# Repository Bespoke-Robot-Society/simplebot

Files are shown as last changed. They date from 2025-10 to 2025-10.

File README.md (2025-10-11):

# SimpleBot

Bespoke Robot Society's original design for kids, students, or cost-sensitive tinkerers.

Image of SimpleBot

Goals:

* Control a basic, multipurpose teaching robot with the Pi Pico (or Pico W).
* Demonstrate **optical odometry** - measuring the distance wheels turn by counting pulses on light sensors.
* Demonstrate **line following** - steer the robot in response to reflectance sensors that give the position of the line.
* Leave pins open on the microcontroller for additional upgrades.
* **Do not exceed $20 in price, with batteries included.**

## Hardware

Simplebot is based on the "Arduino Smart Car" kit that can be found on Amazon or Aliexpress. This provides a caster wheel, two yellow "TT" motors with optical encoder wheels and actual wheels, a power switch, and a 4xAA battery case. (~$6)

For line detectors, a generic "Infrared Obstacle Avoidance Sensor" module can be found in the US for 20 for $10 - SimpleBot requires two ($1).

Microcontroller - Raspberry Pi Pico ($4) or Raspberry Pi Pico W ($6).

Motor Controller - The TB6612FNG dual H-bridge module. You might be able to find this for $1 or less from overseas, but 3 for $9 is available in the US. ($3)

The optical encoder module requires one LED, one photoresistor, five resistors, and one LM393 chip for both. I don't know the prices for these, as I had them on hand.

an MPU6050 (Accelerometer/gyroscope) and nRF24l01 (2.4GHz radio module) are included on the circuit board, but haven't been tested or programmed yet. These occupy the I2C and SPI buses respectively, and would play well with some additional sensors (at the cost of spare pins for more SPI devices).

## Circuit Board

A through-hole (THT) PCB design is available for easy assembly.

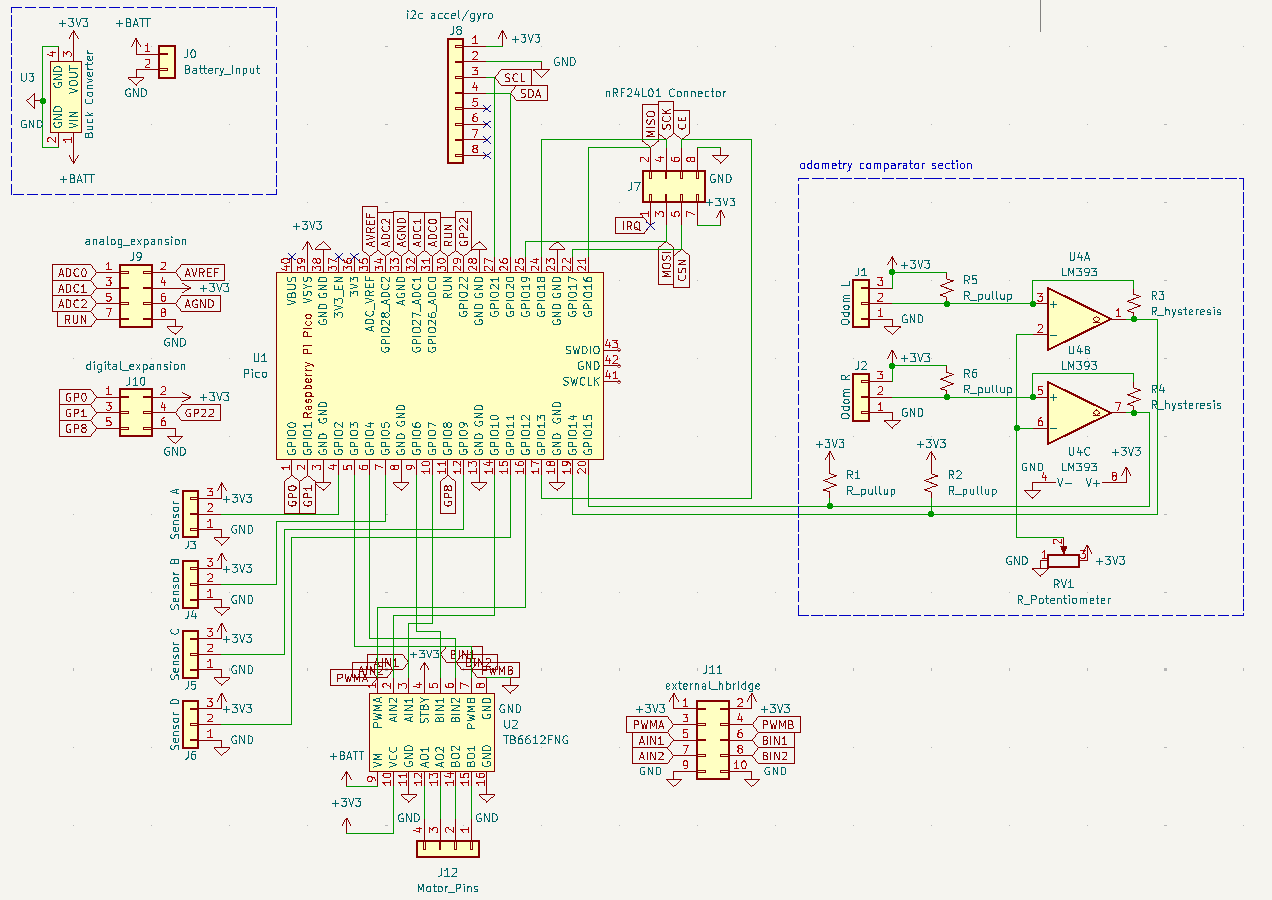
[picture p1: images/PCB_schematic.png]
PCB Schematic


The PCB integrates:
- Raspberry Pi Pico microcontroller (or compatible)
- TB6612FNG motor driver (or external H-bridge support)
- Buck converter for power regulation
- LM393-based optical encoder circuit
- Headers for nRF24L01 radio and MPU6050 IMU
- 4 sensor headers for expansion
- Analog and digital GPIO breakouts

See [PCB_GUIDE.md](PCB_GUIDE.md) for detailed PCB documentation.

See [ASSEMBLY_GUIDE.md](ASSEMBLY_GUIDE.md) for mechanical assembly instructions. 

## Software

Copy the included files to your Pi Pico by USB cable. I used Thonny to test the robot's programs.

# Future Work

Should I switch to an off-the-shelf optical encoder module, or should I build a custom line detecting sensor?

Printed circuit boards:

* Through hole soldering kit
* a board-on-board PCB - same layout as the protoboard, but soldered flat together.
* a custom PCB that uses the ICs from the modules directly

SimpleBot is unfortunately too large for standard micromouse mazes, so a "simplebot mini" seems to be in order.

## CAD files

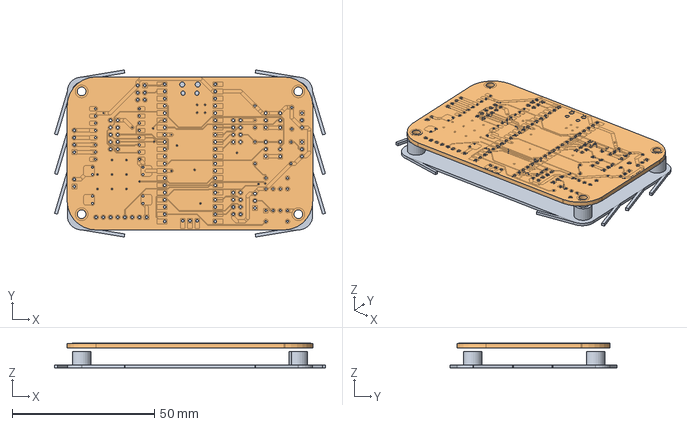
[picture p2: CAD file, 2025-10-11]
diffdrive_PCB_export.FCStd
95.3 x 58.8 x 8.63 mm
Heat_Set_Insert_Version
diffdrive_robot_microcontroller_board 002

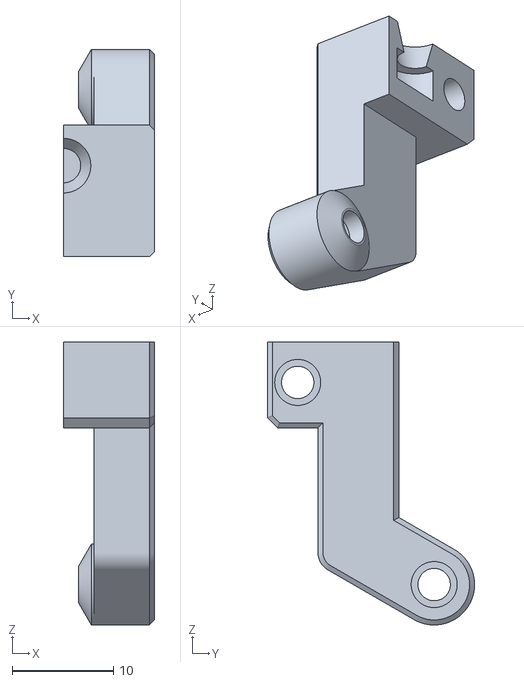
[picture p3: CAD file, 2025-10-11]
STL/Simplebot_caster_rotor.stl
9.00 x 20.5 x 28.0

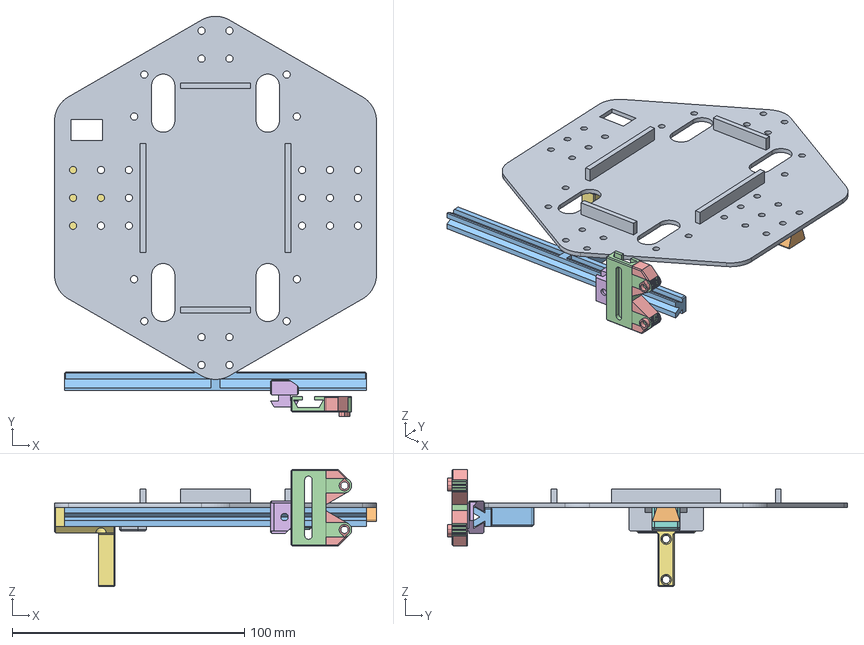
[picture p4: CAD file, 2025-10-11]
Simplebot_oops_all_mountpoints_rev-jason-Aug2025.FCStd
138.6 x 172.3 x 50.5 mm
motor_mount_dovetail_rail
sensor_rail
sensor_vert_slider
sensor_vert_slider_rev1
sensor_horiz_slider_nosupports_ch
mirror_clone_motormount
battery_mount_no_strap_path
battery_mount_wide

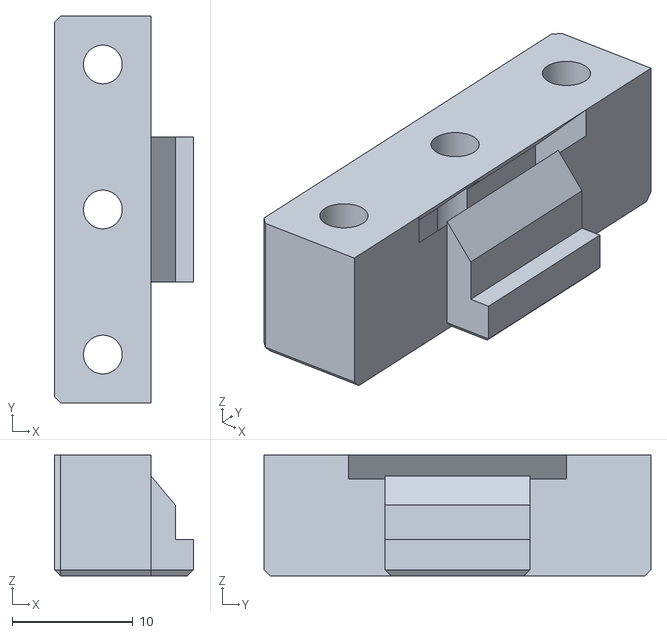
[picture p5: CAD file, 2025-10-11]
STL/Simplebot_battery_mount_wide.stl
11.5 x 32.0 x 10.0

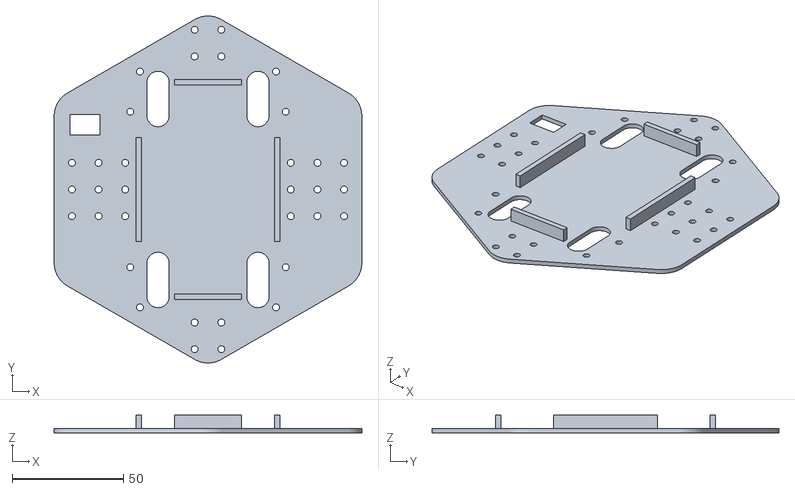
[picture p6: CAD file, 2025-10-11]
STL/Simplebot_chassis.stl
138.6 x 156.3 x 8.00

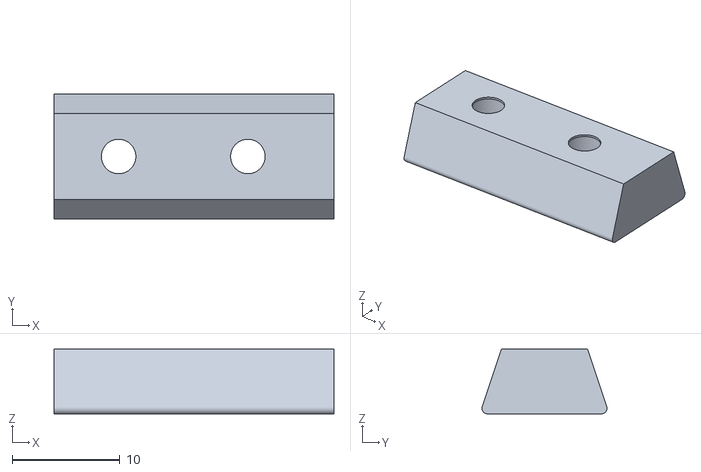
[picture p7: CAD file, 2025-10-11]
STL/Simplebot_motor_mount.stl
26.0 x 11.6 x 6.00

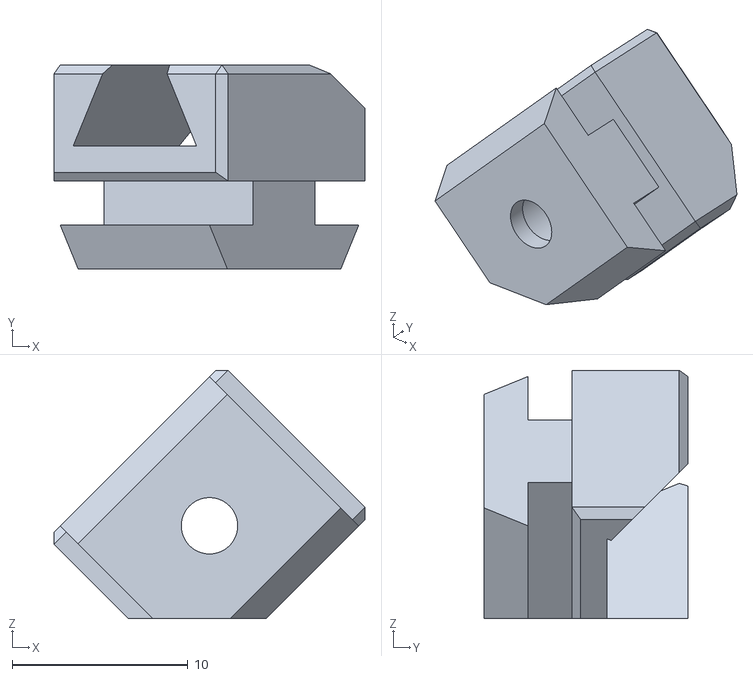
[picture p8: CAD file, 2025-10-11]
STL/Simplebot_sensor_horiz_slider_nosupports_ch.stl
17.7 x 11.6 x 14.1

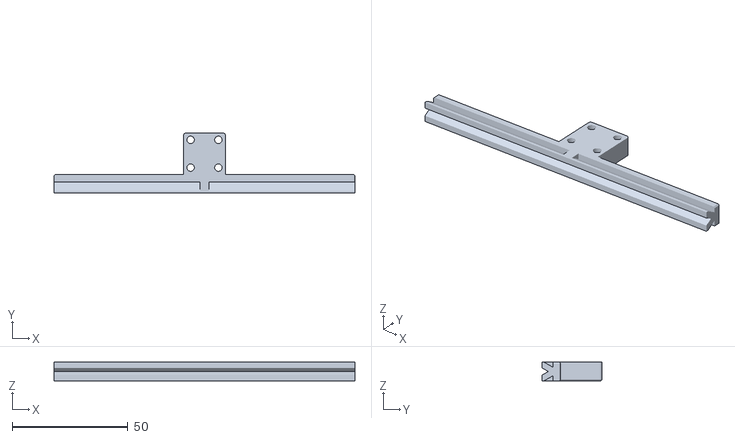
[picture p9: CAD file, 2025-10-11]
STL/Simplebot_sensor_rail.stl
130.0 x 26.0 x 8.00

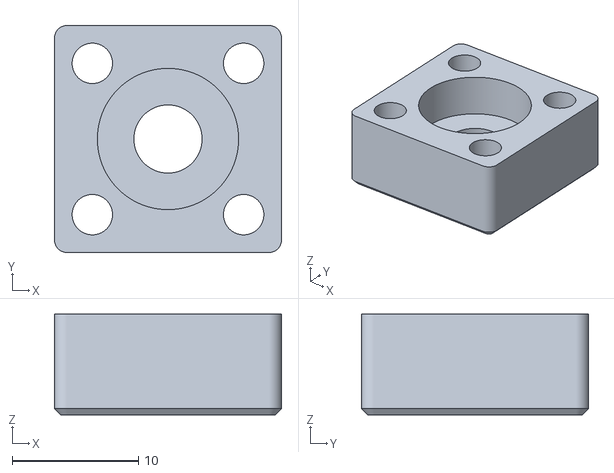
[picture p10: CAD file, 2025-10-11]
STL/Simplebot_caster_stator.stl
18.0 x 18.0 x 8.00

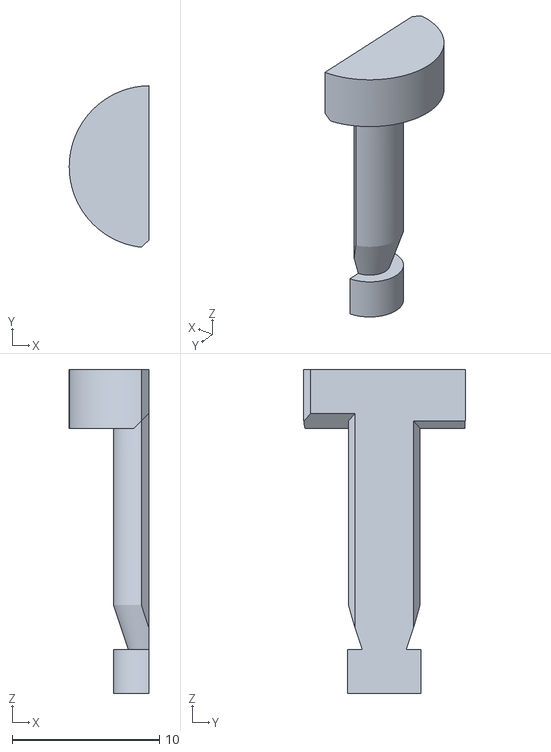
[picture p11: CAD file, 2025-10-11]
STL/Simplebot_caster_pin_half.stl
5.40 x 11.0 x 22.0

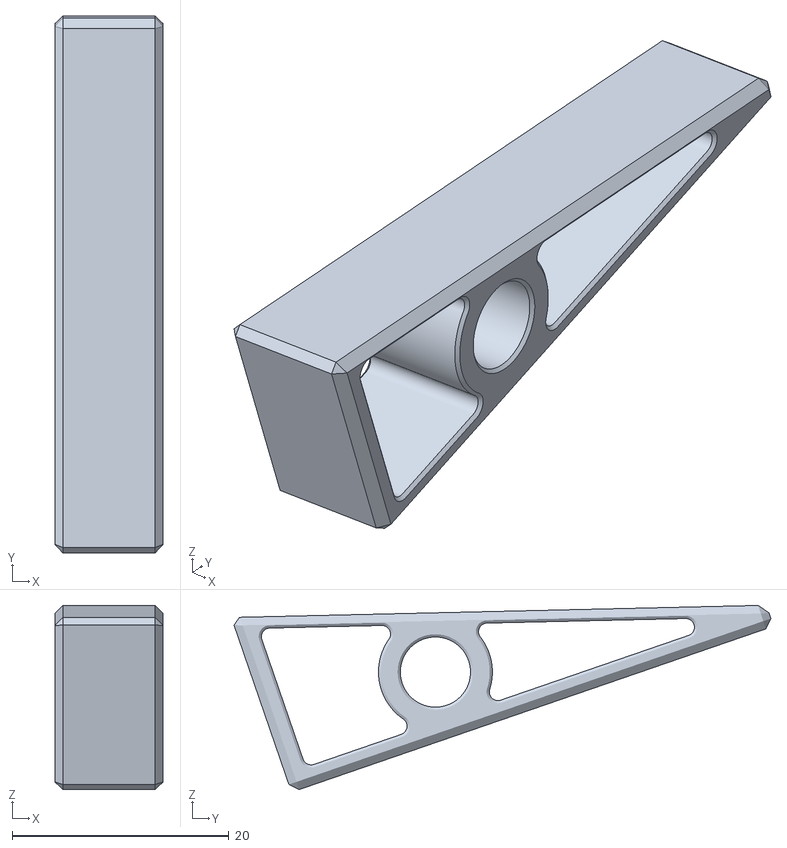
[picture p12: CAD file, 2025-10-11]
STL/low-profile-mount-tilt_mount.stl
10.0 x 49.5 x 17.0

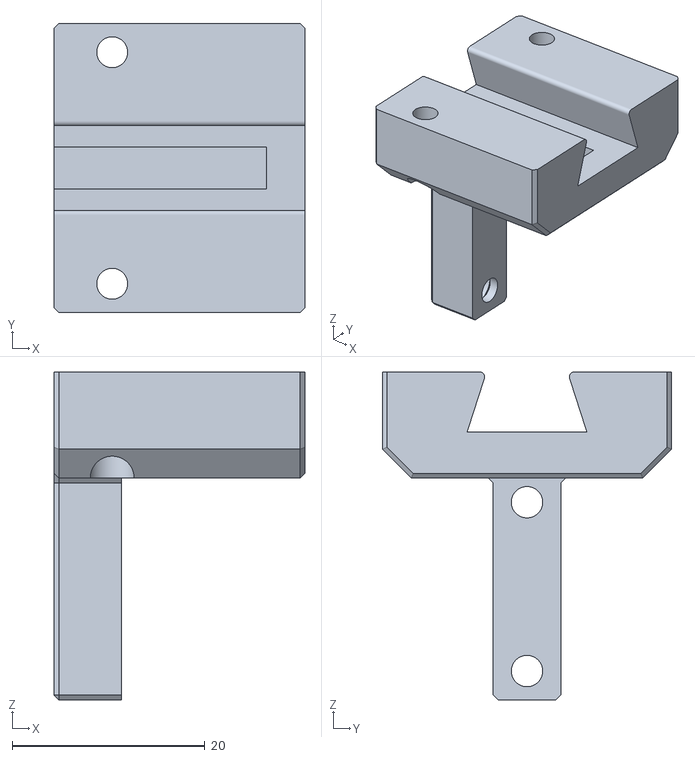
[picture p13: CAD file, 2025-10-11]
STL/Simplebot_motor_post_rev1.stl
26.0 x 30.0 x 34.0

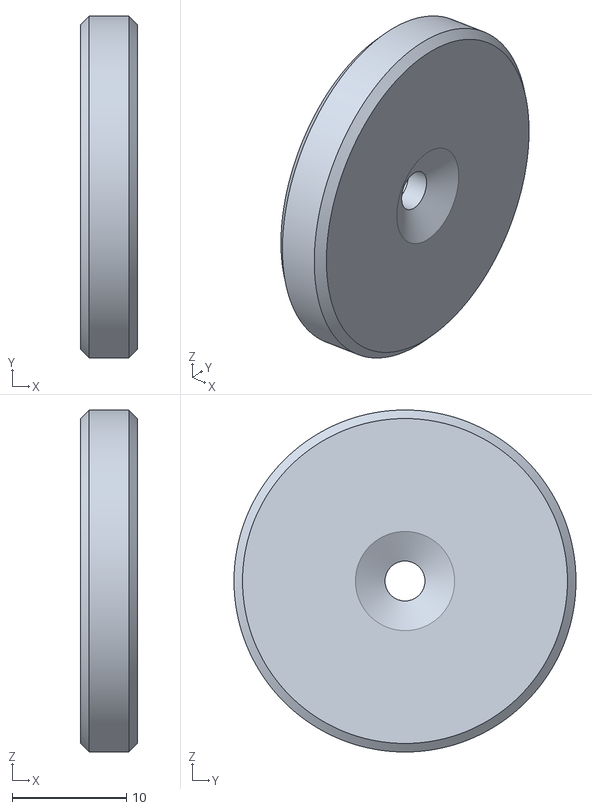
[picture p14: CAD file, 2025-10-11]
STL/Simplebot_caster_wheel.stl
5.00 x 30.0 x 30.0

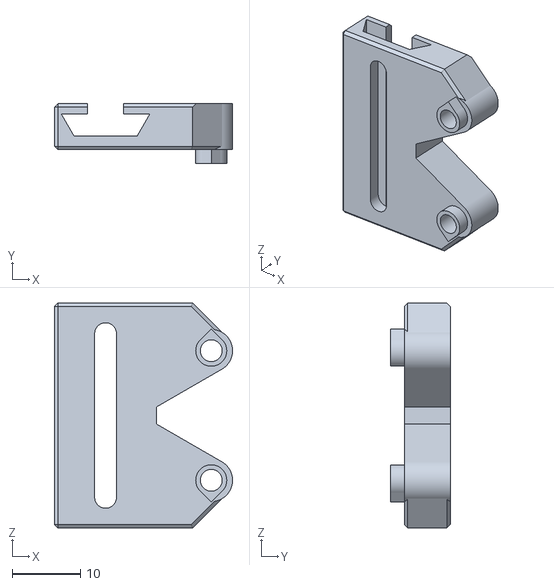
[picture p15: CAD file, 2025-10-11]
STL/Simplebot_sensor_vert_slider_rev1.stl
26.1 x 8.75 x 33.0

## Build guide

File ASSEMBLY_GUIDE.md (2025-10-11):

# SimpleBot Assembly Guide

This guide covers the mechanical assembly of SimpleBot's 3D-printed components.

## Required Hardware
- 4xAA battery holder
- 2x TT motors with wheels
- 1x caster wheel (ball or omni)
- 2x line sensor modules
- Heat set inserts (M3 recommended)
- M3 screws (various lengths)
- Velcro strap for battery retention

## Assembly Overview

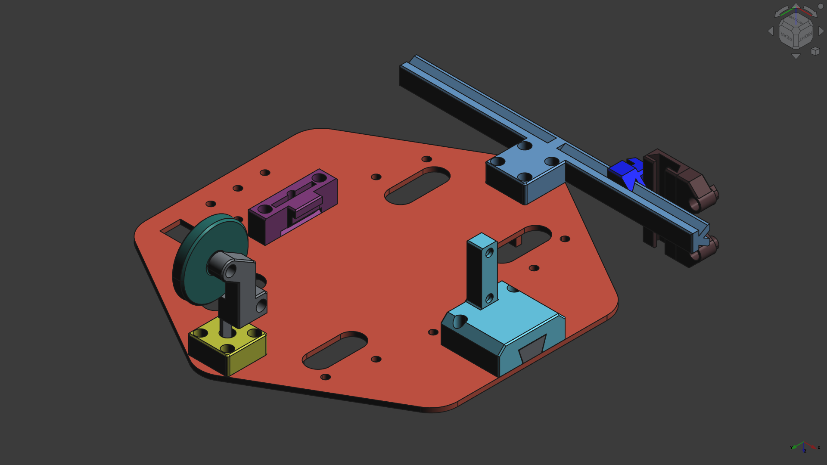
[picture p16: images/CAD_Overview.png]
CAD Overview


The SimpleBot chassis consists of several 3D-printed modules that attach to the main chassis plate.

---

## Chassis

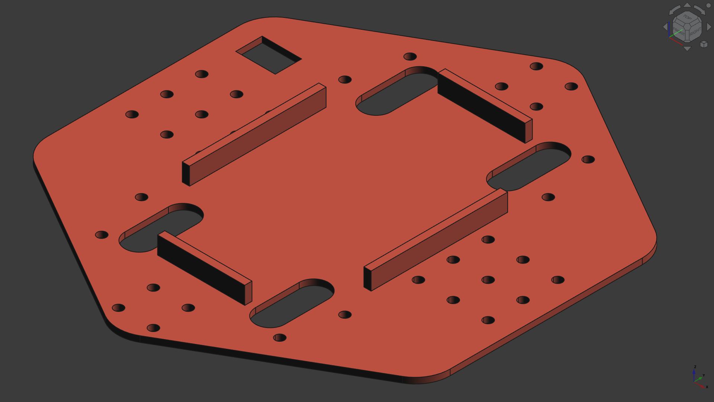
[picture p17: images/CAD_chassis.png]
Chassis


The main chassis plate serves as the foundation for all other components. All assembly steps attach to this plate.

---

## Battery Block

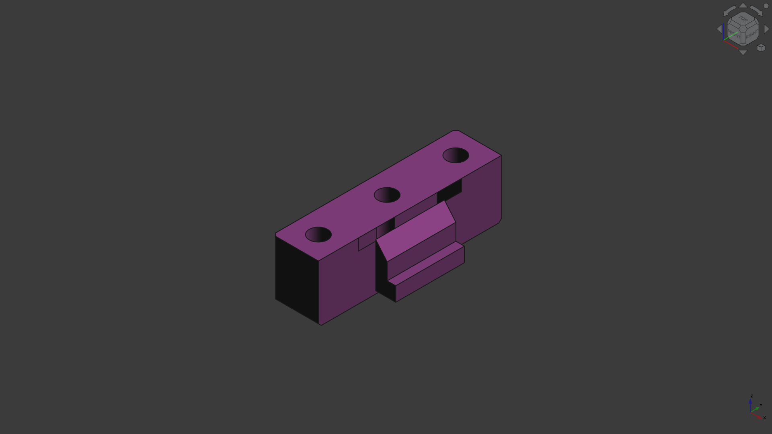
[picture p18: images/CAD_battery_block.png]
Battery Block


The battery block holds a 4xAA battery holder to the bottom of the chassis. It features a slot for a velcro strap, which holds the batteries in place and counteracts sagging from the weight of the batteries pulling down on the thin chassis plate.

**Assembly:**
- Install heat set inserts as needed
- Attach to chassis with screws
- Thread velcro strap through slot before final attachment

---

## Caster Assembly

### Caster Block
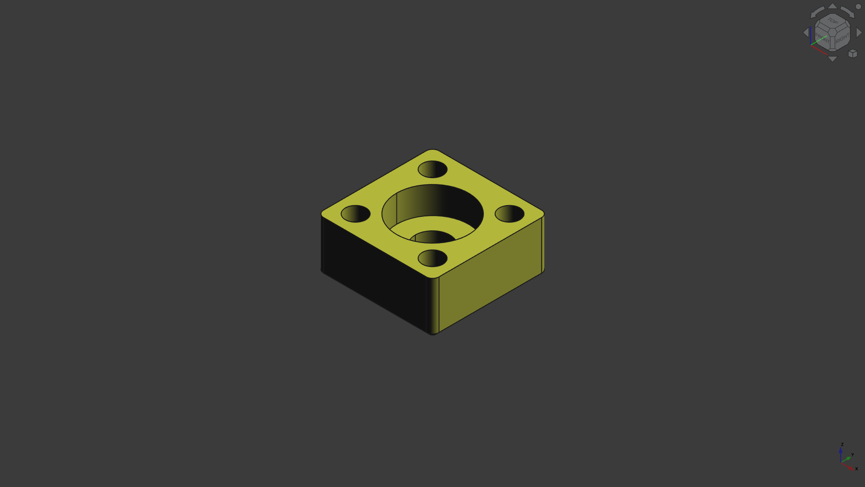
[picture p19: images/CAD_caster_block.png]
Caster Block


**Heat set inserts:** 4

### Caster Arm
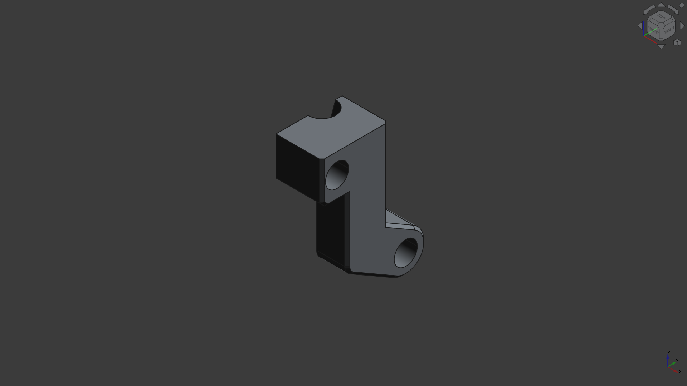
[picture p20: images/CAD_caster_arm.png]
Caster Arm


**Heat set inserts:** 2 (in one arm only)

**Note:** One caster arm must be 3D printed mirrored to create a matching pair.

### Caster Pin
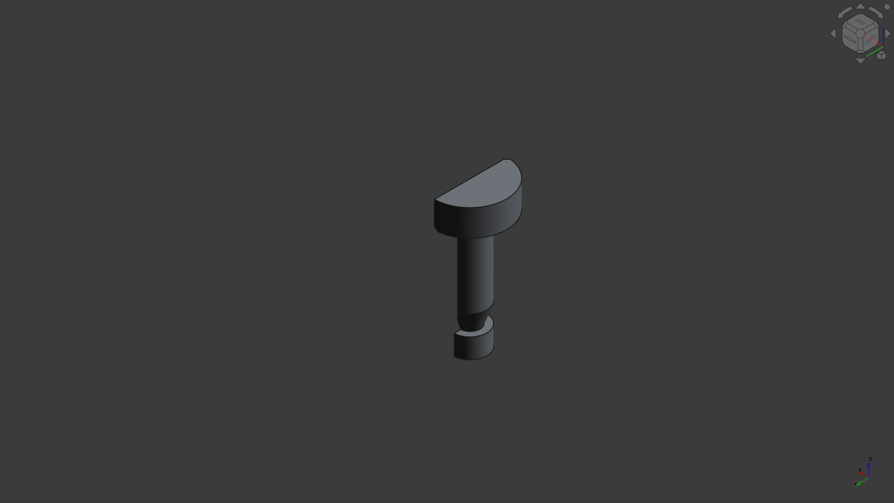
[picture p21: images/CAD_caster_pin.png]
Caster Pin


This is a "half pin" designed to print flat without supports. Two pins are required.

### Caster Wheel
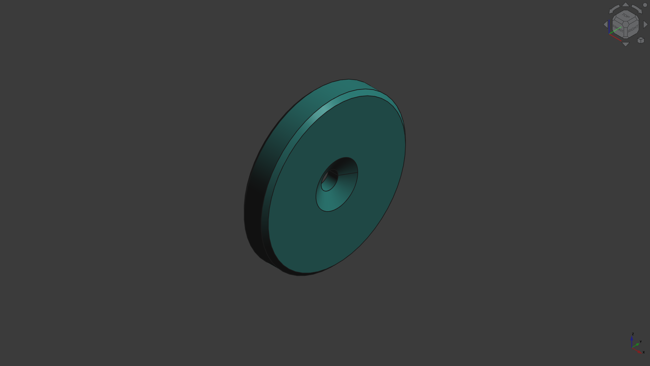
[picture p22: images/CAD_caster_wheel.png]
Caster Wheel


**Assembly Steps:**
1. Install 4 heat set inserts in the caster block
2. Install 2 heat set inserts in one caster arm
3. Insert two caster pins through the caster block
4. Position both caster arms around the bottom of the pins and around the caster wheel
5. Attach block to chassis with 4 screws
6. Join the two arms together with 2 screws (one serves as the wheel axle)

---

## Motor Mounts

### Dovetail
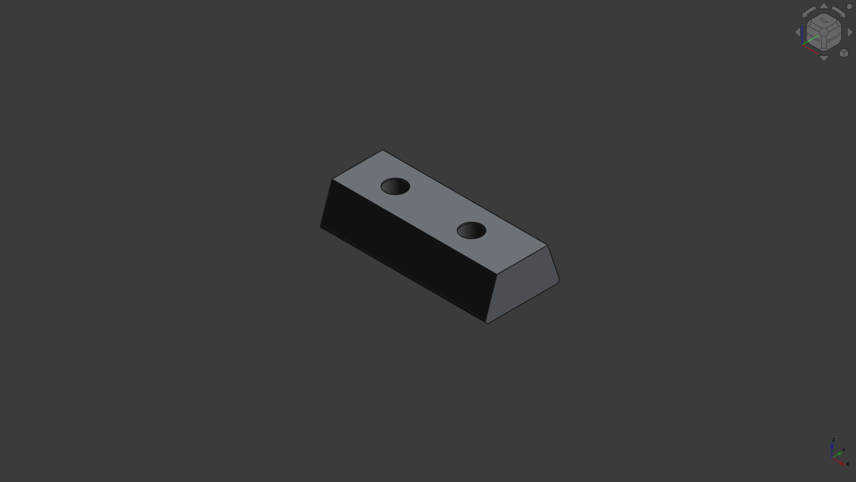
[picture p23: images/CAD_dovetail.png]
Dovetail


**Heat set inserts:** 2

### Motor Mount
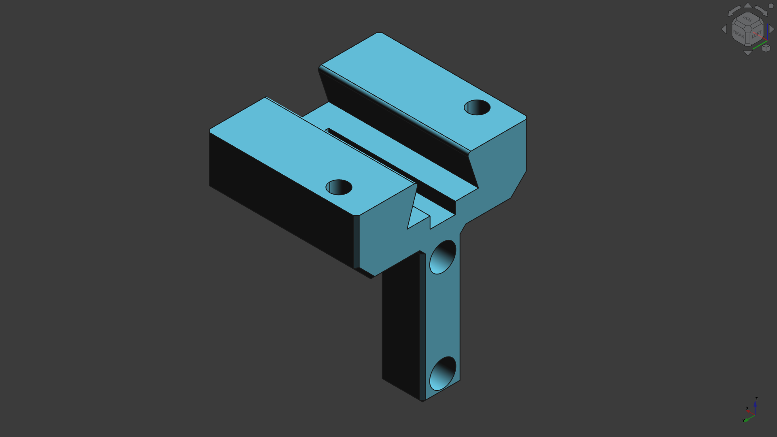
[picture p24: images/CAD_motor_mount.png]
Motor Mount


**Heat set inserts:** 3 (2 for motor, 1-2 for mount-to-dovetail attachment)

**Note:** These are symmetrical parts requiring 1x per side (2x total to mount both wheels).

**Assembly Steps:**
1. Install dovetail first to chassis (2 heat set inserts, 2 screws)
2. Mount motor to motor mount (2 screws into 2 heat set inserts)
3. Attach motor mount to chassis via dovetail (1-2 screws into heat set inserts)
4. Secure motor with single screw to prevent sliding

**Current Design Note:** No different attachments available at this time.

---

## Sensor System

### Sensor Rail
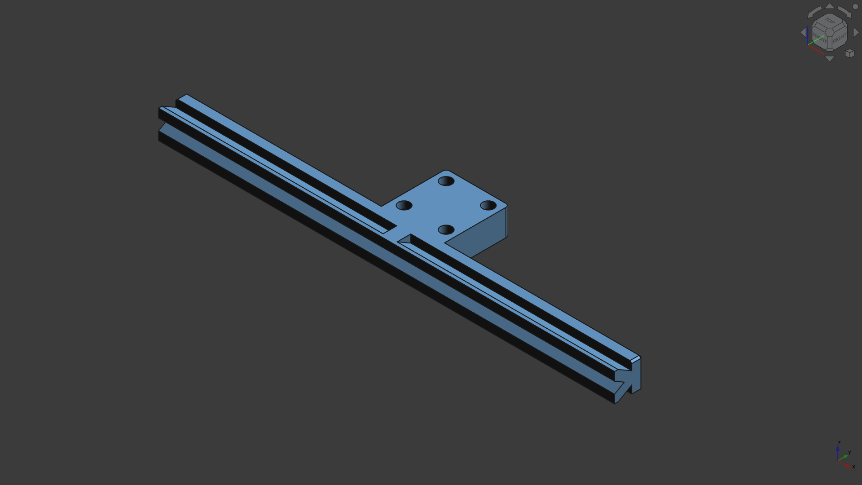
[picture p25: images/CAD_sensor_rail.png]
Sensor Rail


The sensor rail mounts to the underside of the chassis.

**Hardware:** 4 heat set inserts / 4 screws

### Sensor Block
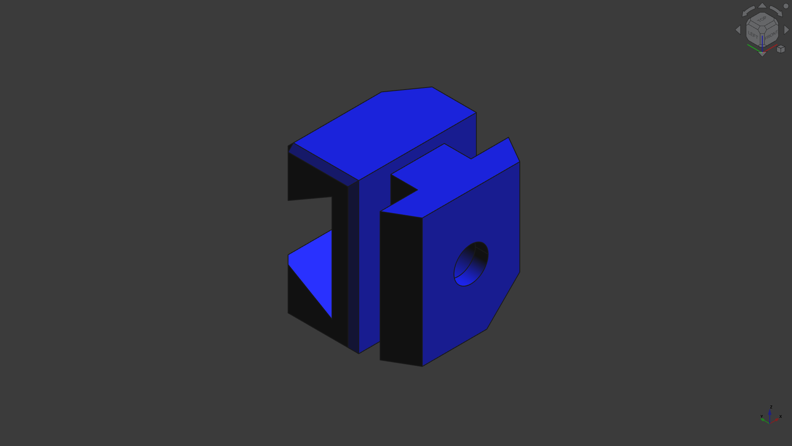
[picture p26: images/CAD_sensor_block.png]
Sensor Block


**Required:** 2x sensor blocks
**Heat set inserts per block:** 1

**Note:** One block *can* be printed mirrored for symmetry, but the cutout feature is only for printability (no supports needed) and doesn't require mirroring for function.

### Sensor Sled
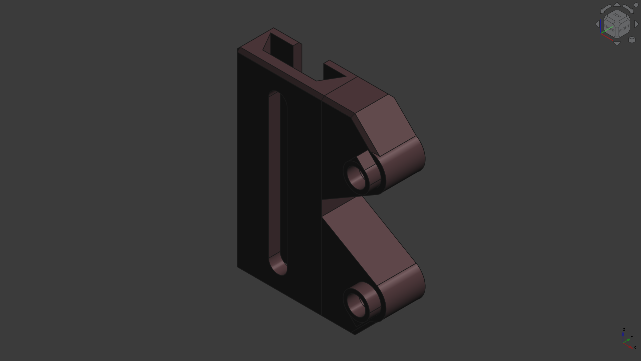
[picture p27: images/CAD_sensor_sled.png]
Sensor Sled


**Required:** 2x sensor sleds
**Heat set inserts per sled:** 1

**Note:** The sled is symmetrical - print twice in the same orientation, then flip one over and install the heat set insert in the opposite hole.

**Assembly Steps:**
1. Attach sensor rail to underside of chassis (4 screws into 4 heat set inserts)
2. Slide one sensor block onto the rail
3. Install 1 heat set insert in the sensor block
4. Slide sensor sled onto sensor block
5. Install 1 heat set insert in the sled
6. Attach line sensor module:
   - One screw through PCB hole into sled
   - Another screw goes through sled slot into sensor block
7. Adjust position by sliding block along rail and sled along block
8. Tighten screw until it bites slightly into sensor rail to lock position
9. Repeat for second sensor

**Design Note:** The unused hole in the sled aligns with a flat spot on the back of the line sensor PCB, providing support without requiring a screw.

---

## Final Assembly Checklist

- [ ] Battery block installed with velcro strap
- [ ] Caster assembly complete and secure
- [ ] Both motor mounts installed with motors
- [ ] Sensor rail attached to chassis
- [ ] Both sensor blocks and sleds installed
- [ ] Line sensors positioned and secured
- [ ] PCB mounted (see PCB_GUIDE.md)
- [ ] All wiring complete

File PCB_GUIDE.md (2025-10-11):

# SimpleBot PCB Guide

This guide explains the PCB design, functionality, and assembly instructions.

## PCB Overview

PCB Schematic

The SimpleBot PCB is built around a Raspberry Pi Pico microcontroller (or compatible) and integrates all necessary electronics for a complete differential drive robot with optical odometry and line following capabilities.

### Compatible Microcontrollers
You can use any 40-pin microcontroller with the same ground, PWM, and power pinout as the Pico:
- Raspberry Pi Pico (official or knockoff)
- Raspberry Pi Pico W
- Raspberry Pi Pico 2
- Raspberry Pi Pico 2 W

### Key Features
- **Microcontroller:** Pi Pico or compatible (40-pin header)
- **Motor Control:** TB6612FNG module with external H-bridge support
- **Power Management:** Adjustable buck converter for 3.3V regulation
- **Odometry:** LM393 comparator with voltage divider for optical encoders
- **Expansion:**
  - nRF24L01 radio header (SPI)
  - MPU6050 IMU header (I2C)
  - 4 dedicated sensor headers (GPIO + 3.3V + GND)
  - Analog expansion header
  - Digital expansion header

**Note:** The nRF24L01 and I2C gyro headers are designed for specific sensors but can be used as general GPIO if needed.

---

## PCB Sections

### Power Section

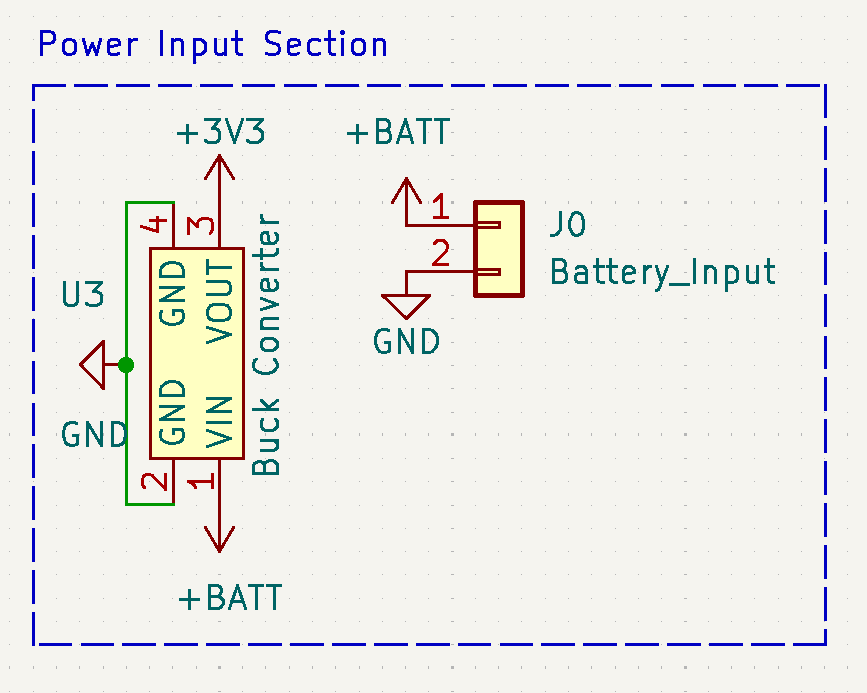
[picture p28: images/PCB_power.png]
Power Section


The power section manages battery input and voltage regulation.

**Components:**
- Buck converter module (adjustable)
- Power switch
- Battery input terminals

**IMPORTANT - Pre-Assembly Setup:**
1. **Tune buck converter to 3.3V BEFORE soldering** to the PCB
2. Use a multimeter to verify output voltage
3. Connect power switch to disable battery power when USB cable is inserted

**Power Flow:**
- 4xAA batteries (6V nominal) → Power switch → Buck converter → 3.3V regulated output
- USB power available when connected to Pico

---

### Motor Control Section

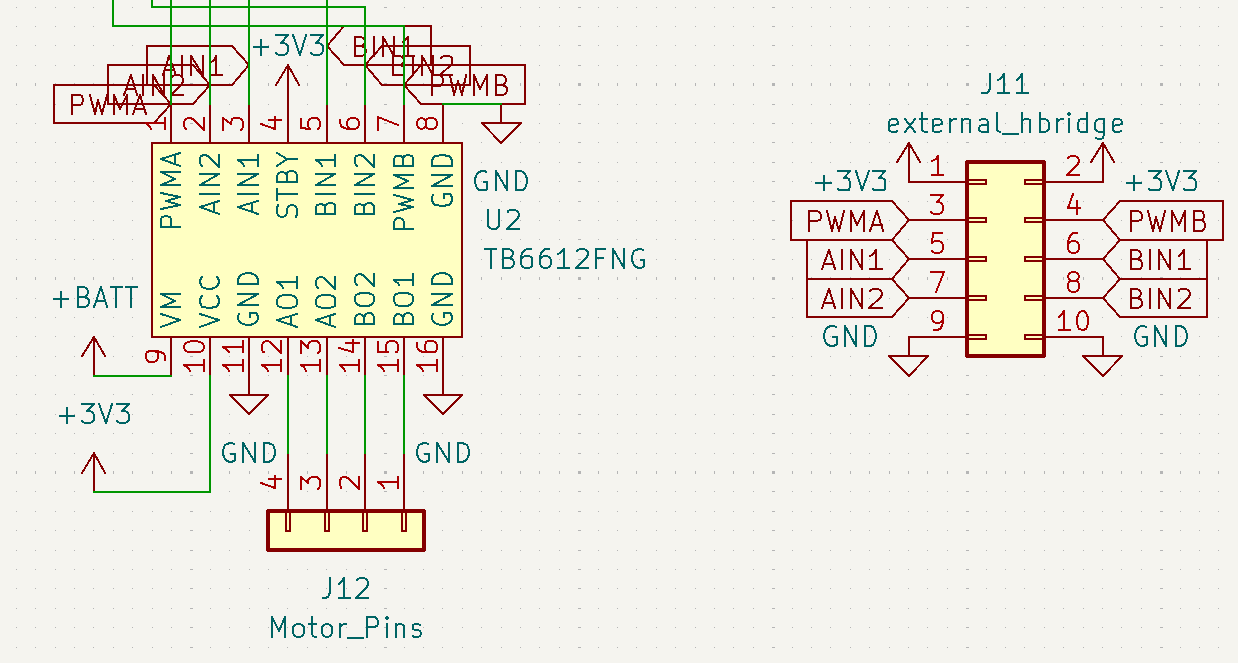
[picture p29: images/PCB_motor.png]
Motor Section


The motor section uses a TB6612FNG dual H-bridge module.

**Standard Configuration:**
- TB6612FNG module solders directly to PCB
- Controls two TT motors independently
- PWM speed control for both motors

**Advanced Configuration - External H-Bridge:**
Underneath the TB6612FNG module position, a 2x5 DuPont pin header can be installed. This header provides:
- PWM signals (both motors)
- IN1/IN2 direction control (both motors)
- 3.3V logic power
- Ground

**Benefit:** Use a larger external H-bridge for more powerful motors while using the **exact same Python code** - the control signals are identical.

**Motor Connections:**
- Motor A: Left wheel
- Motor B: Right wheel
- Connect encoder discs to optical encoder section

---

### Optical Encoder (Odometry) Section

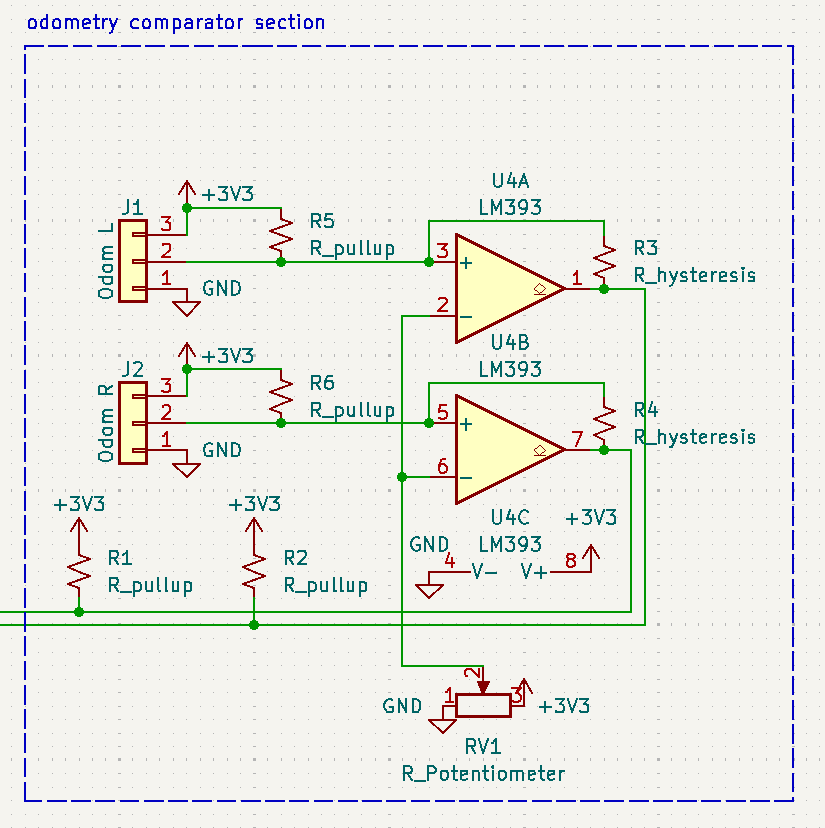
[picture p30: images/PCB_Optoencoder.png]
Optical Encoder Section


The odometry section reads slotted encoder wheels to measure distance traveled.

**Components:**
- LM393 dual comparator
- Voltage divider circuit
- Analog sensor inputs (2 channels)

**Sensor Configuration:**
- LED shines through encoder wheel slots
- Photoresistor detects light/dark transitions
- LM393 converts analog signal to clean digital pulses
- Pico counts pulses to calculate wheel rotation

**Each Channel:**
- 1x LED (through encoder slot)
- 1x Photoresistor
- Voltage divider resistors
- Comparator output to Pico GPIO

---

## PCB Layers and Manufacturing

### All Layers View
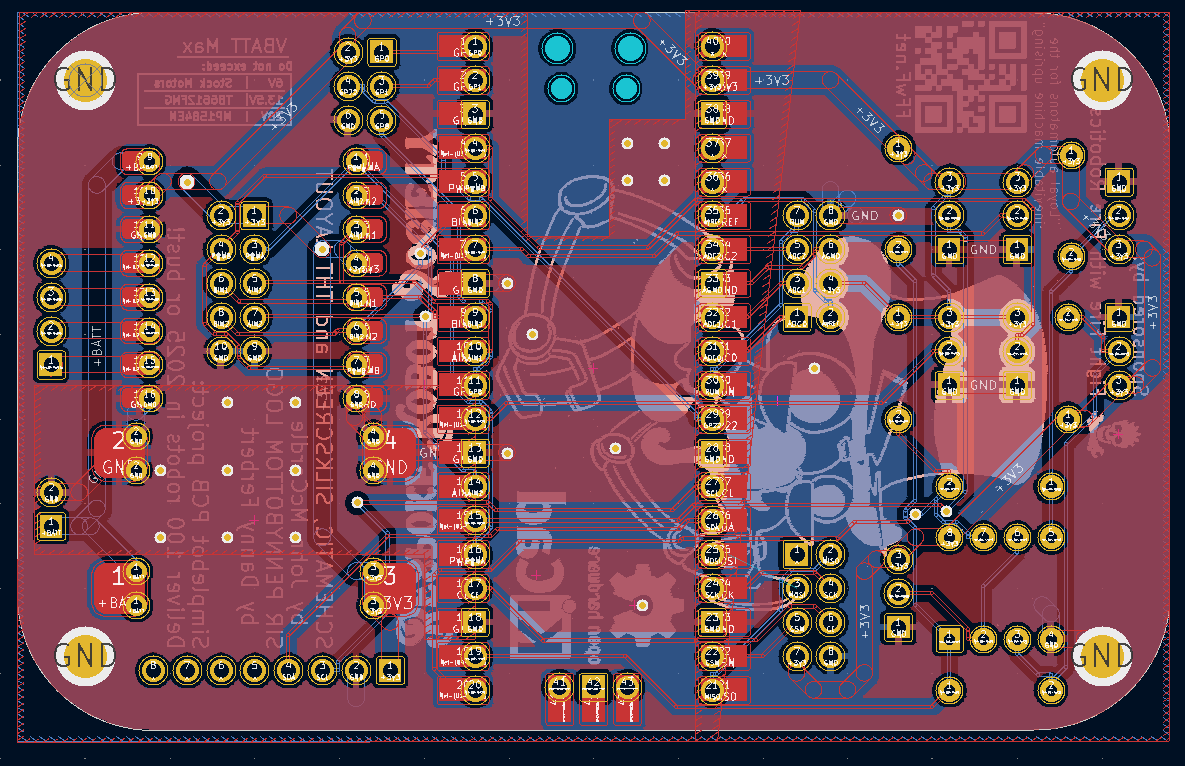
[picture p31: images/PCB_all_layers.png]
PCB All Layers


Complete view of all PCB layers for manufacturing reference.

### Front View
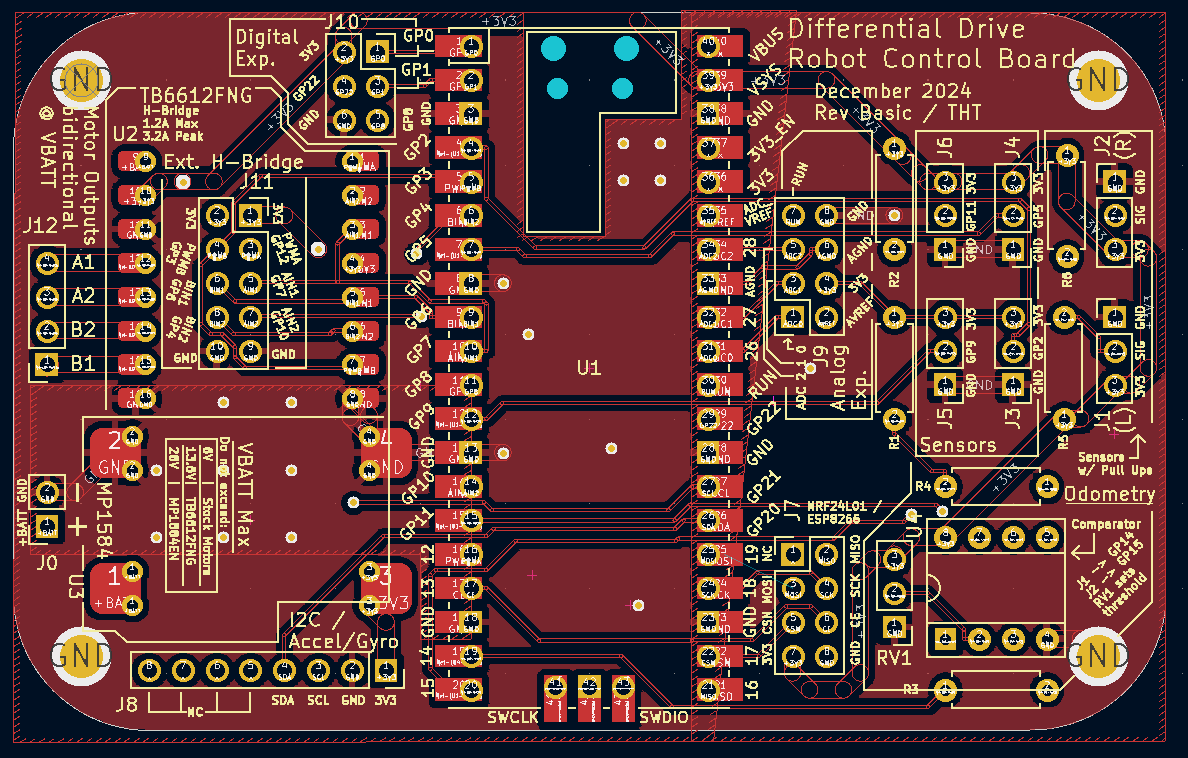
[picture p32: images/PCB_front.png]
PCB Front


Component placement on the top side of the PCB.

### Back View
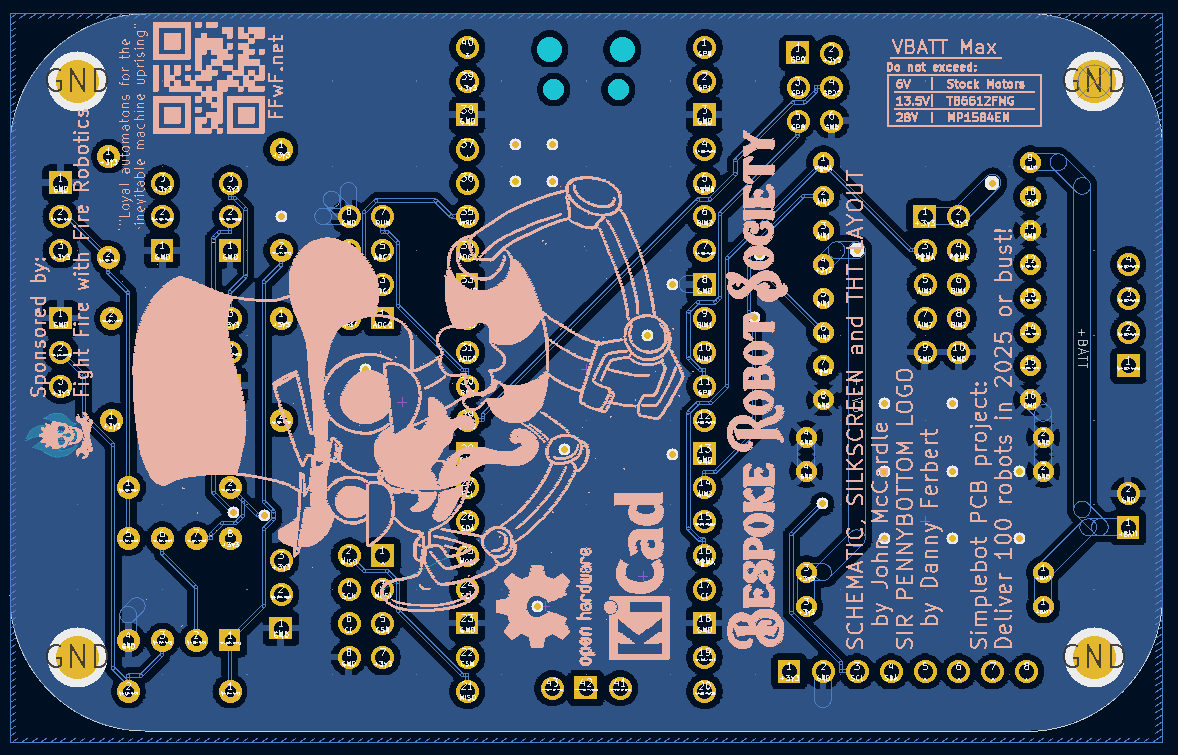
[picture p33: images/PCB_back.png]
PCB Back


Bottom side of the PCB (primarily traces and ground plane).

---

## Assembly Instructions

The SimpleBot PCB uses through-hole components for easy assembly with basic soldering equipment. This makes it ideal for educational builds and beginners.

### Step 1: Power Section
1. Verify buck converter outputs 3.3V (CRITICAL!)
2. Solder buck converter to PCB
3. Install power switch
4. Test voltage output before proceeding

### Step 2: Pico Socket
1. Solder 40-pin headers for Pico
2. Insert Pico (do not solder Pico directly - use sockets for easy replacement)

### Step 3: Motor Controller
1. Solder TB6612FNG module directly to PCB
   - OR -
2. Install 2x5 pin header for external H-bridge (underneath TB6612 position)

### Step 4: Optical Encoder Circuit
1. Install LM393 IC
2. Install resistors for voltage divider
3. Solder LED holders/headers
4. Solder photoresistor terminals

### Step 5: Expansion Headers
1. Install nRF24L01 header (if using radio)
2. Install MPU6050 header (if using IMU)
3. Install 4x sensor headers
4. Install analog/digital expansion headers

### Step 6: Testing
1. Connect USB power to Pico
2. Verify 3.3V on all power rails
3. Test motor outputs (no motors connected yet)
4. Check encoder circuit outputs
5. Install in chassis and connect motors

---

## Gerber Files

PCB manufacturing files are available in the repository:
- `diffdrive_robot_microcontroller_board--tht_Gerber.zip`

Upload this file to your preferred PCB manufacturer (JLCPCB, PCBWay, OSH Park, etc.).

---

## Software

See the main [README.md](README.md) for software installation and programming instructions.

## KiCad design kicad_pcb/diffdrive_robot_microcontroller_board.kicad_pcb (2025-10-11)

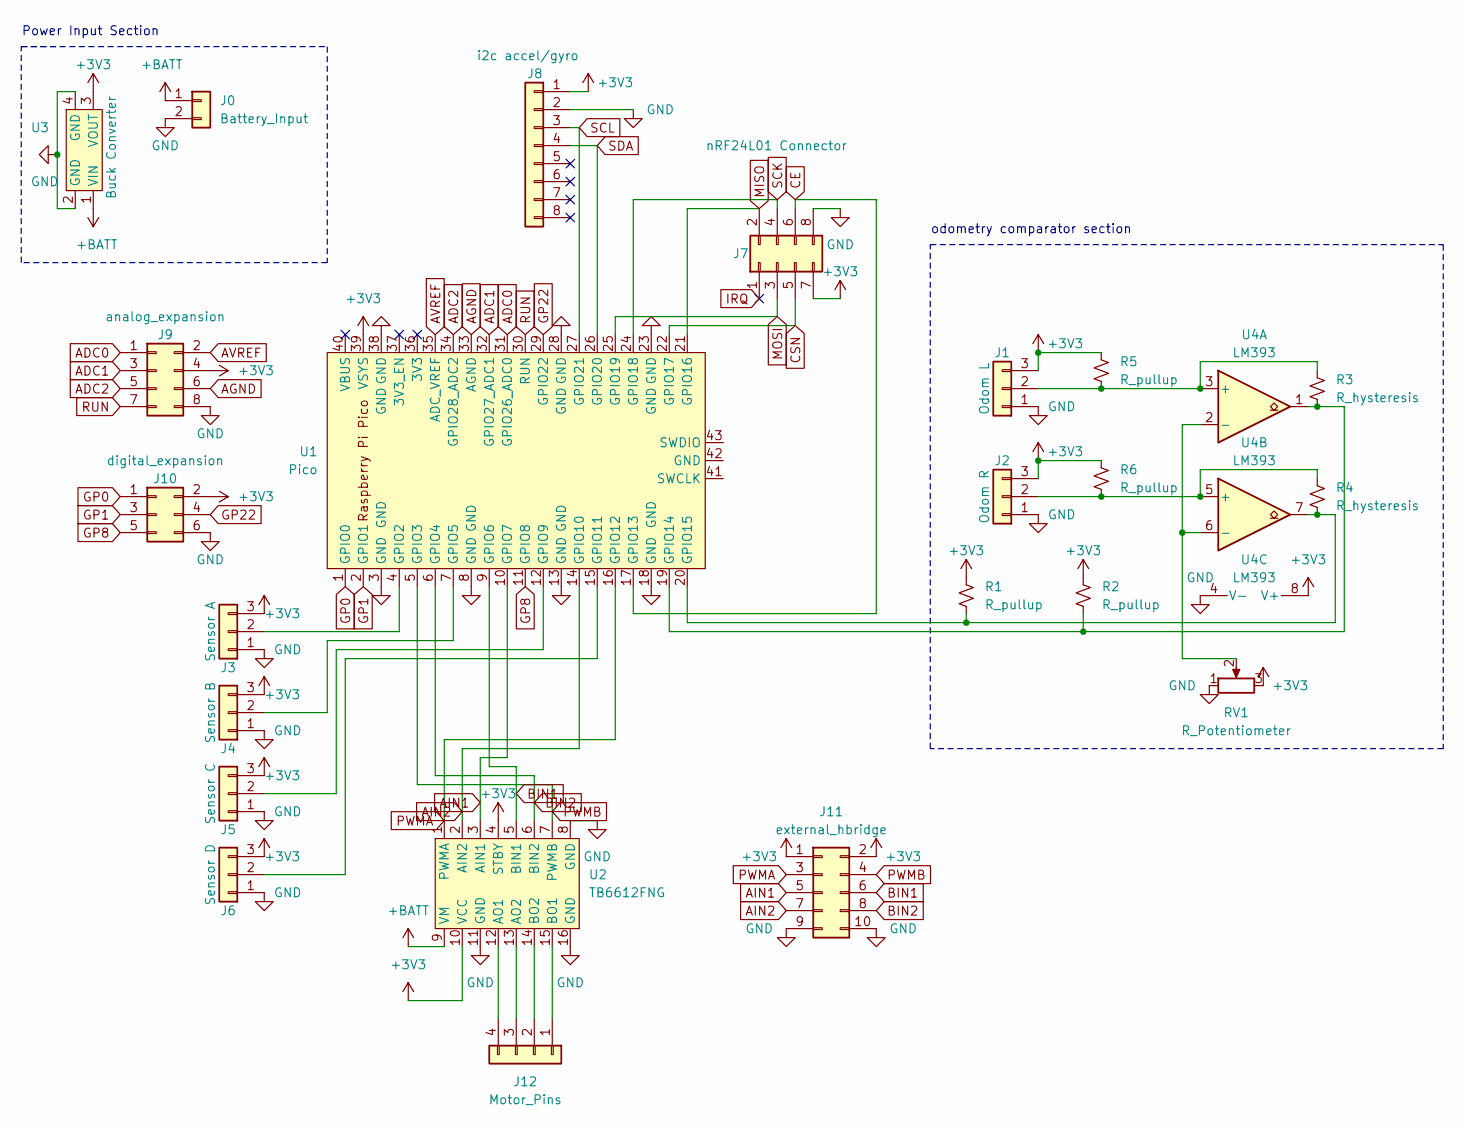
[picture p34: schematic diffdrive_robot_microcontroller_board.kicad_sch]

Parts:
J0: Battery_Input; PinSocket_1x02_P2.54mm_Vertical
J1: Odom L; PinHeader_1x03_P2.54mm_Vertical
J2: Odom R; PinHeader_1x03_P2.54mm_Vertical
J3: Sensor A; PinHeader_1x03_P2.54mm_Vertical
J4: Sensor B; PinHeader_1x03_P2.54mm_Vertical
J5: Sensor C; PinHeader_1x03_P2.54mm_Vertical
J6: Sensor D; PinHeader_1x03_P2.54mm_Vertical
J7: nRF24L01 Connector; PinSocket_2x04_P2.54mm_Vertical
J8: i2c accel/gyro; PinSocket_1x08_P2.54mm_Vertical
J9: analog_expansion; PinSocket_2x04_P2.54mm_Vertical
J10: digital_expansion; PinSocket_2x03_P2.54mm_Vertical
J11: external_hbridge; PinSocket_2x05_P2.54mm_Vertical
J12: Motor_Pins; PinSocket_1x04_P2.54mm_Vertical
R1, R2, R5, R6: R_pullup; R_Axial_DIN0207_L6.3mm_D2.5mm_P7.62mm_Horizontal
R3, R4: R_hysteresis; R_Axial_DIN0207_L6.3mm_D2.5mm_P7.62mm_Horizontal
RV1: R_Potentiometer; PinHeader_1x03_P2.54mm_Vertical
U1: Pico; RPi_Pico_SMD_TH
U2: TB6612FNG; TB6612FNG_Breakout
U3: Buck Converter; BuckConverter_Breakout
U4: LM393; DIP-8_W7.62mm_Socket

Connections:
+3V3: J1.3, J2.3, J3.3, J4.3, J5.3, J6.3, J7.7, J8.1, J9.4, J10.2, J11.1, J11.2, R1.1, R2.1, R5.1, R6.1, RV1.3, U1.39 (VSYS), U2.4 (STBY), U2.10 (VCC), U3.3 (VOUT), U4.8 (V+)
+BATT: J0.1, U2.9 (VM), U3.1 (VIN)
ADC0: J9.1, U1.31 (GPIO26_ADC0)
ADC1: J9.3, U1.32 (GPIO27_ADC1)
ADC2: J9.5, U1.34 (GPIO28_ADC2)
AGND: J9.6, U1.33 (AGND)
AIN1: J11.5, U1.10 (GPIO7), U2.3 (AIN1)
AIN2: J11.7, U1.14 (GPIO10), U2.2 (AIN2)
AVREF: J9.2, U1.35 (ADC_VREF)
BIN1: J11.6, U1.9 (GPIO6), U2.5 (BIN1)
BIN2: J11.8, U1.6 (GPIO4), U2.6 (BIN2)
CE: J7.6, U1.17 (GPIO13)
CSN: J7.5, U1.22 (GPIO17)
GND: J0.2, J1.1, J2.1, J3.1, J4.1, J5.1, J6.1, J7.8, J8.2, J9.8, J10.6, J11.9, J11.10, RV1.1, U1.3 (GND), U1.8 (GND), U1.13 (GND), U1.18 (GND), U1.23 (GND), U1.28 (GND), U1.38 (GND), U2.8 (GND), U2.11 (GND), U2.16 (GND), U3.2 (GND), U3.4 (GND), U4.4 (V-)
GP0: J10.1, U1.1 (GPIO0)
GP1: J10.3, U1.2 (GPIO1)
GP8: J10.5, U1.11 (GPIO8)
GP22: J10.4, U1.29 (GPIO22)
IRQ: J7.1
MISO: J7.2, U1.21 (GPIO16)
MOSI: J7.3, U1.25 (GPIO19)
unnamed: J1.2, R3.2, R5.2, U4.3 (+)
unnamed: J3.2, U1.4 (GPIO2)
unnamed: J4.2, U1.7 (GPIO5)
unnamed: J5.2, U1.12 (GPIO9)
unnamed: J6.2, U1.15 (GPIO11)
unnamed: R1.2, R4.2, U1.20 (GPIO15), U4.7
unnamed: J12.4, U2.12 (AO1)
unnamed: J12.3, U2.13 (AO2)
unnamed: J12.2, U2.14 (BO2)
unnamed: J12.1, U2.15 (BO1)
unnamed: R2.2, R3.1, U1.19 (GPIO14), U4.1
unnamed: RV1.2, U4.2 (-), U4.6 (-)
unnamed: J2.2, R4.1, R6.2, U4.5 (+)
PWMA: J11.3, U1.16 (GPIO12), U2.1 (PWMA)
PWMB: J11.4, U1.5 (GPIO3), U2.7 (PWMB)
RUN: J9.7, U1.30 (RUN)
SCK: J7.4, U1.24 (GPIO18)
SCL: J8.3, U1.27 (GPIO21)
SDA: J8.4, U1.26 (GPIO20)

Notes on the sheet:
odometry comparator section
Power Input Section

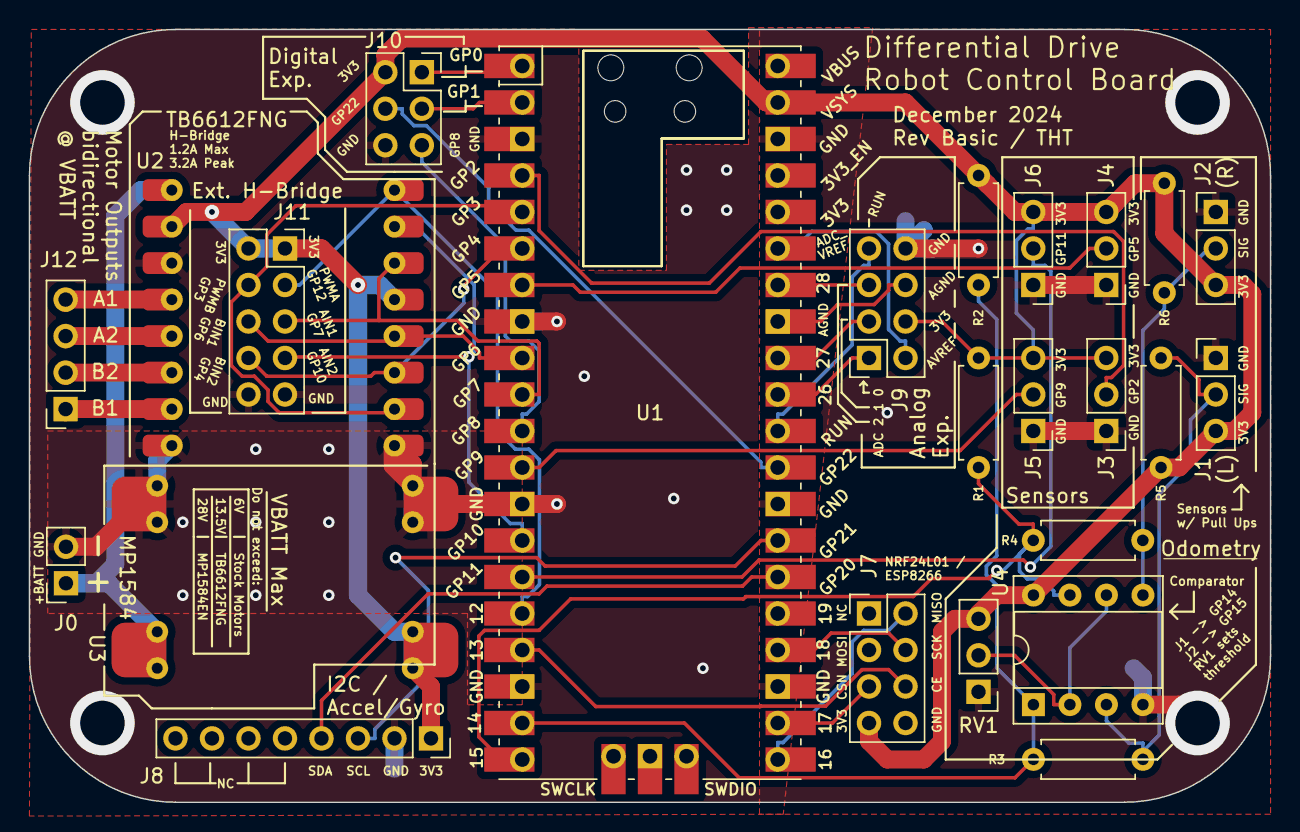
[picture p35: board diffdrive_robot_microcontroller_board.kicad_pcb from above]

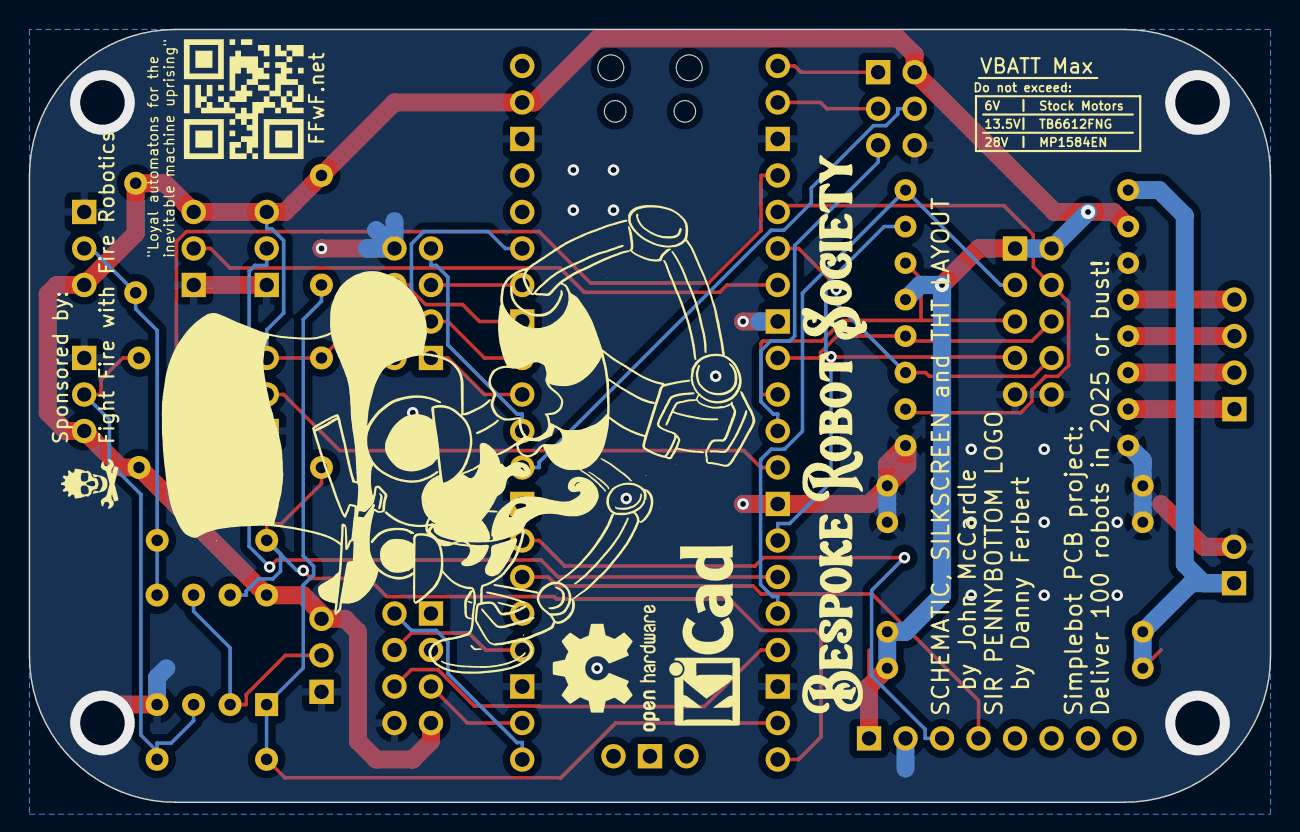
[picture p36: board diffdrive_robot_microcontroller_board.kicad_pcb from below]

Board: 2 copper layers, 86.4 x 53.8 mm, 26 parts (3 on the bottom side), 39 nets.

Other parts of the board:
G1: LOGO; BRS_LOGO
G2: LOGO; BRS_TEXT

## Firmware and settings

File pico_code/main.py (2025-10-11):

#motor.py
from machine import Pin, PWM
import time

class Motor:
    def __init__(self, pwm_pin, in1_pin, in2_pin):
        self.pwm = PWM(Pin(pwm_pin), freq=50, duty_u16=8192)
        self.pwm.duty_u16(0) # 0%
        self.dir_pins = (Pin(in1_pin, Pin.OUT), Pin(in2_pin, Pin.OUT))
        
    def forward(self, speed=None):
        self.dir_pins[0].value(0)
        self.dir_pins[1].value(1)
        if speed: self.speed(speed)
        
    def reverse(self, speed=None):
        self.dir_pins[1].value(0)
        self.dir_pins[0].value(1)
        if speed: self.speed(speed)
        
    def stop(self):
        self.dir_pins[0].value(0)
        self.dir_pins[1].value(0)
    
    def speed(self, percent):
        self.pwm.duty_u16(int((percent/100) * 65535)) # 0%
        
#bot.py
class SimpleBot:
    def __init__(self, left_motor, right_motor):
        self.left = left_motor
        self.right = right_motor
        
    def forward(self, speed=50):
        self.left.forward(speed)
        self.right.forward(speed)
        
    def cw(self, speed=50):
        self.left.forward(speed)
        self.right.reverse(speed)
        
    def ccw(self, speed=50):
        self.left.reverse(speed)
        self.right.forward(speed)
        
    def reverse(self, speed=50):
        self.left.forward(speed)
        self.right.forward(speed)
        
    def stop(self):
        self.left.stop()
        self.right.stop()
        

l, r = Pin(11, Pin.PULL_DOWN), Pin(9, Pin.PULL_DOWN)
values = [0, 0]

SPEED=50

#line following test
m = Motor(12, 10, 7)
n = Motor(3, 4, 6)

def say(_l, _r):
    if _r and _l:
        print("reverse (blocked)")
    elif _l:
        print("ccw (steer right)")
    elif _r:
        print("cw (steer left)")
    else:
        print("forward (on the line)")

bot = SimpleBot(m, n)
_l, _r = 0, 0
while True:
    _l = l.value()
    if _l != values[0]:
        print("9 (left) became", _l)
        values[0] = _l
        say(_l, _r)

    _r = r.value()
    if _r != values[1]:
        print("11 (right) became", _r)
        values[1] = _r
        say(_l, _r)
    
    if _r and _l:
        bot.reverse(SPEED)
    elif _l:
        bot.ccw(SPEED)
    elif _r:
        bot.cw(SPEED)
    else:
        bot.forward(SPEED)
    time.sleep(0.025)

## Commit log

2024-12-26 Initial (THT) board designs, autorouted with freerouting-2.0.1
    [diffdrive_robot_microcontroller_board.kicad_pcb, diffdrive_robot_microcontroller_board.kicad_sch]
2025-10-11 August through October 2025 CAD revisions
    [Simplebot_battery_mount_wide.stl, Simplebot_caster_pin_half.stl, Simplebot_caster_rotor.stl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]
